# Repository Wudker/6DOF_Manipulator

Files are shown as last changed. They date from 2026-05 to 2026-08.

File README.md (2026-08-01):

# Educational 6-DOF Robotic Manipulator – Engineering Thesis

This project presents an educational anthropomorphic robotic manipulator with six degrees of freedom, developed as an engineering thesis. It combines mechanical design, kinematic analysis, embedded control, custom electronics and software development. The system uses an ESP32 and a custom PCB to control six stepper-driven joints through a local web interface. Forward and inverse kinematics provide position control, while repeatability and positioning tests were used to validate the adopted assumptions and identify the prototype’s mechanical limitations.

## Technologies

`ESP32` `C/C++` `Forward kinematics` `Inverse kinematics` `WebServer` `Stepper motors` `DRV8825` `Custom PCB` `Belt transmissions` `3D printing` `CAD`

## Usage and development status

After assembling the hardware and uploading the firmware, the manipulator can be controlled through its local web interface. Before starting movement, verify the wiring, power supply and initial joint positions. The prototype was successfully built and tested; potential improvements include increased mechanical stiffness, more accurate calibration and smoother trajectory planning.

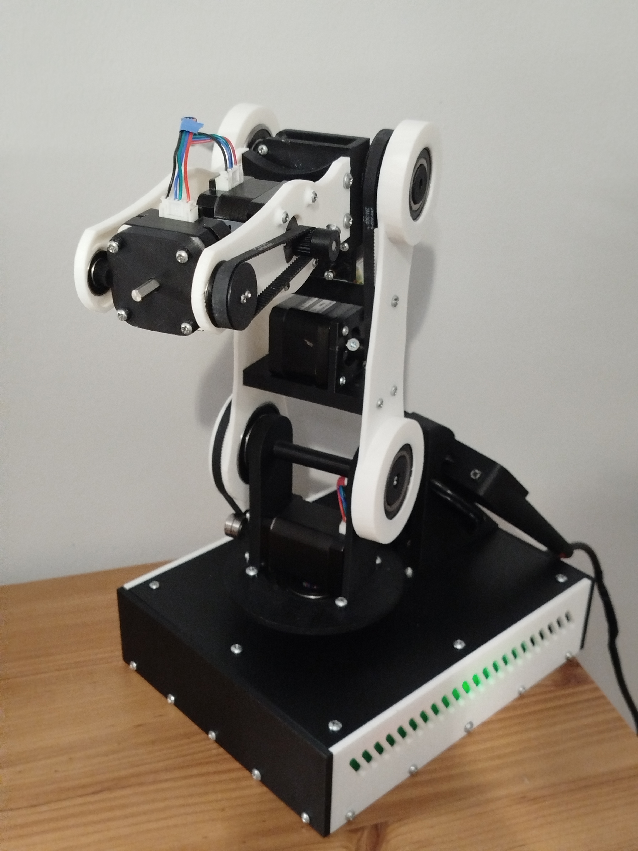
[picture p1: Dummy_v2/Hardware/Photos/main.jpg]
Prototype


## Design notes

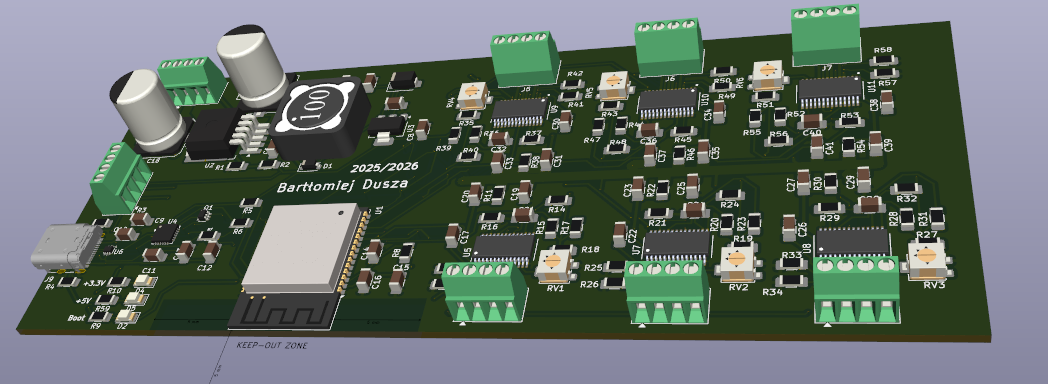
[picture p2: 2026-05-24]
Dummy_v2/Hardware/Photos/PCB_photos/Screenshot_12.png

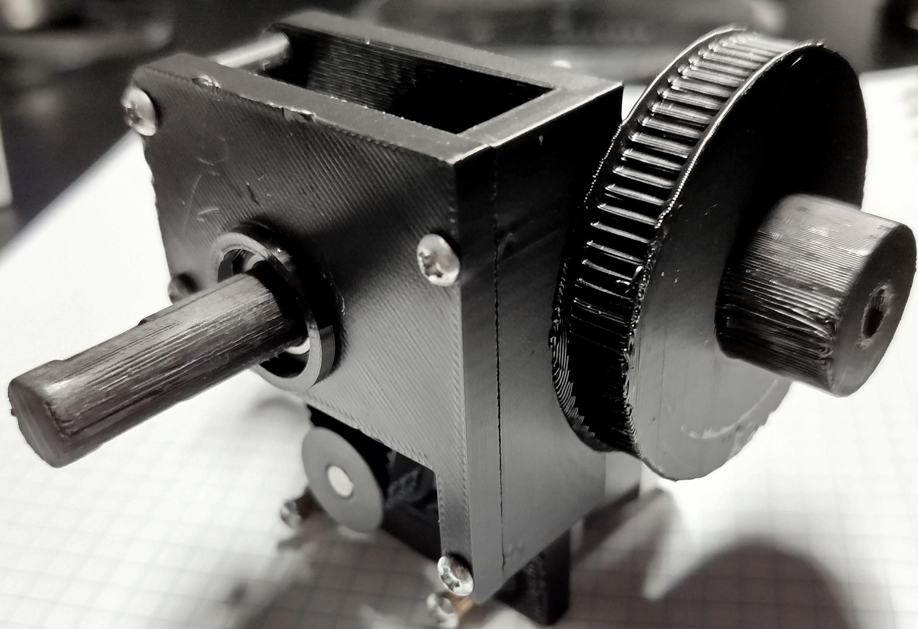
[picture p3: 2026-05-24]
Dummy_v2/Hardware/Photos/real_przegub_4.jpg

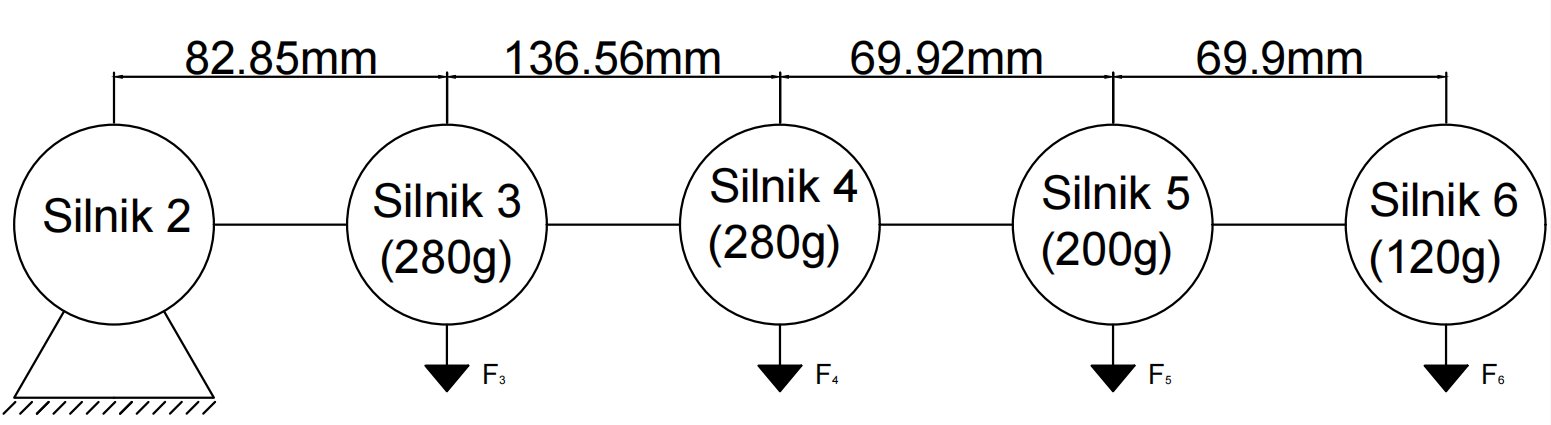
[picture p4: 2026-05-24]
Dummy_v2/Hardware/Photos/momenty_przykład_obliczen.png

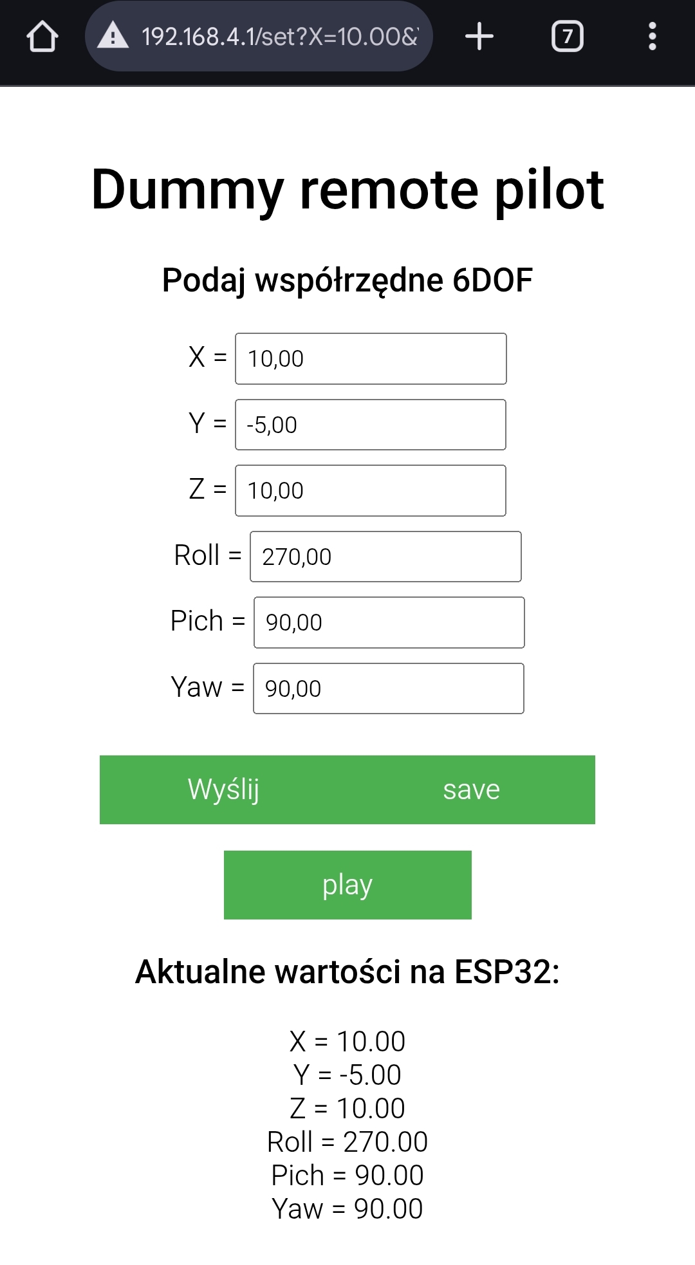
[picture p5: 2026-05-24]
Dummy_v2/Hardware/Photos/Remote (1).jpg

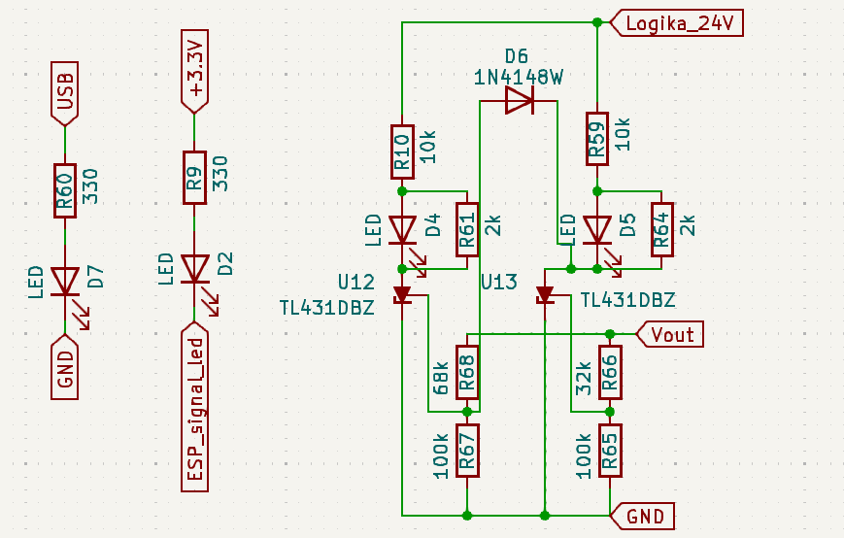
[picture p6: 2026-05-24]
Dummy_v2/Hardware/Photos/PCB_photos/PCB_indycators.png

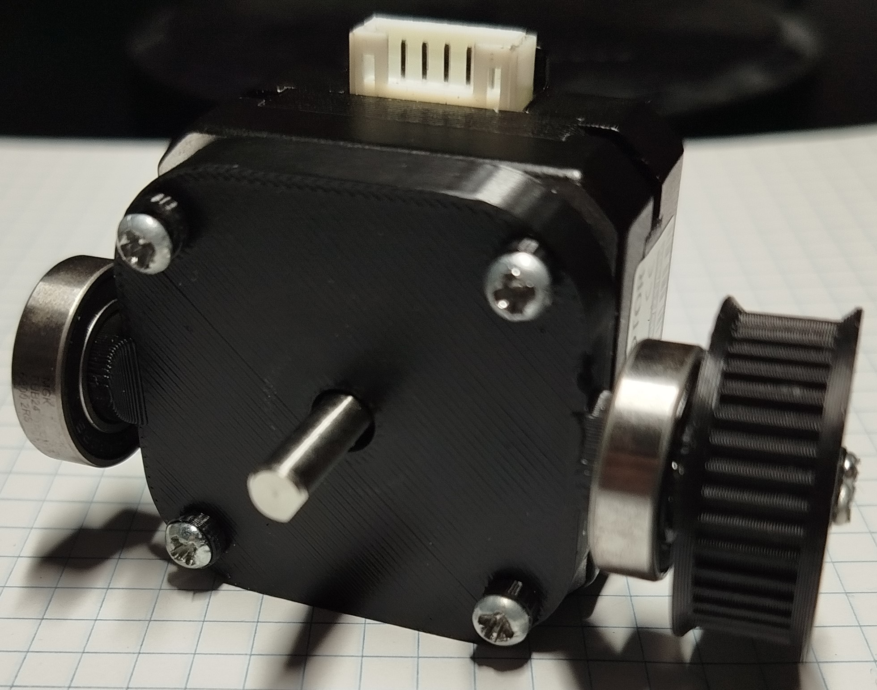
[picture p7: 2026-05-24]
Dummy_v2/Hardware/Photos/real_przegub_6.jpg

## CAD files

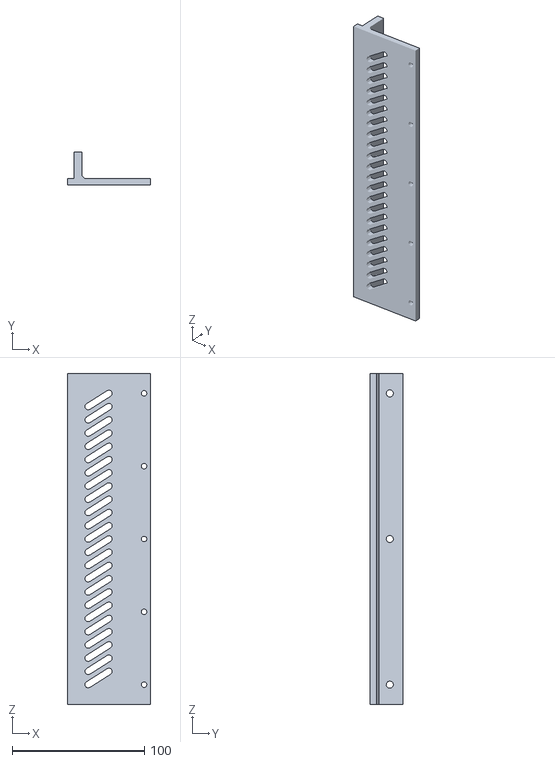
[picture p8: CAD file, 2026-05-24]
Dummy_v2/Hardware/Model/podstawa/podstawa_sciana_bok.stl
63.0 x 25.0 x 250.0

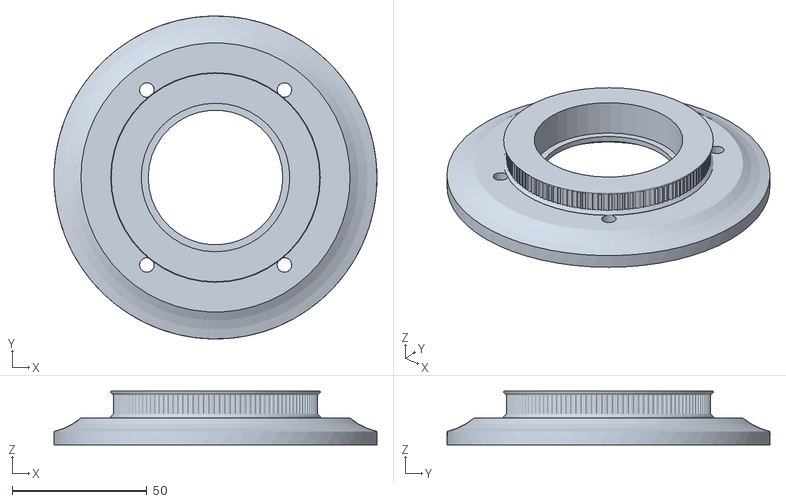
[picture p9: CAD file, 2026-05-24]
Dummy_v2/Hardware/Model/przegub_1/podstawa_platforma.stl
120.0 x 120.0 x 20.0

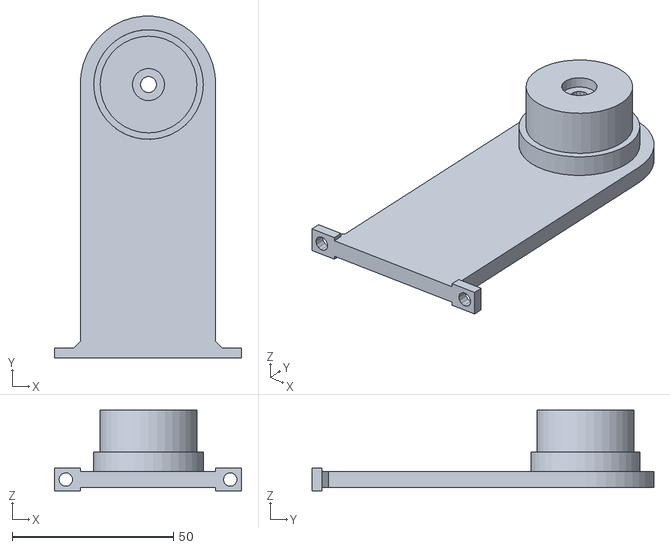
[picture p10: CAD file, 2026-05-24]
Dummy_v2/Hardware/Model/przegub_2/baza_rama_cz2.stl
58.0 x 105.9 x 25.0

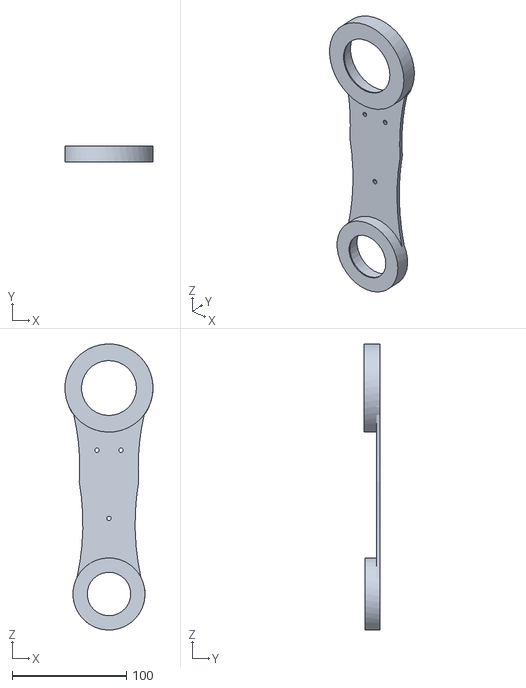
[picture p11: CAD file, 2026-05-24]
Dummy_v2/Hardware/Model/przegub_3/baza_rama3.stl
77.0 x 14.0 x 249.9

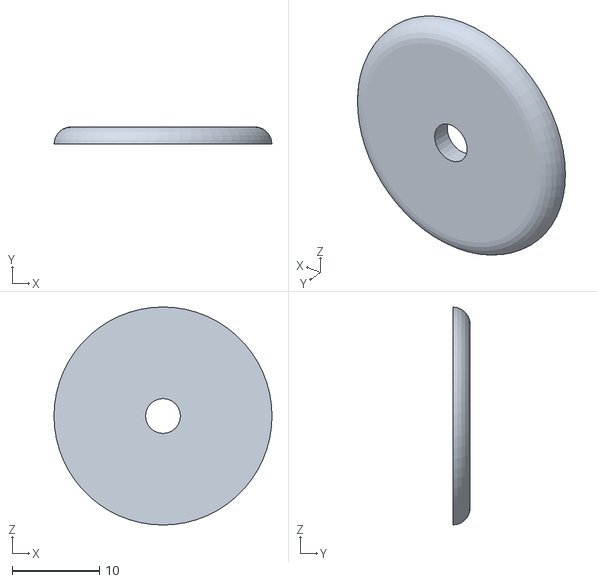
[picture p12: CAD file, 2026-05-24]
Dummy_v2/Hardware/Model/przegub_4/OBUD.stl
25.0 x 2.00 x 25.0

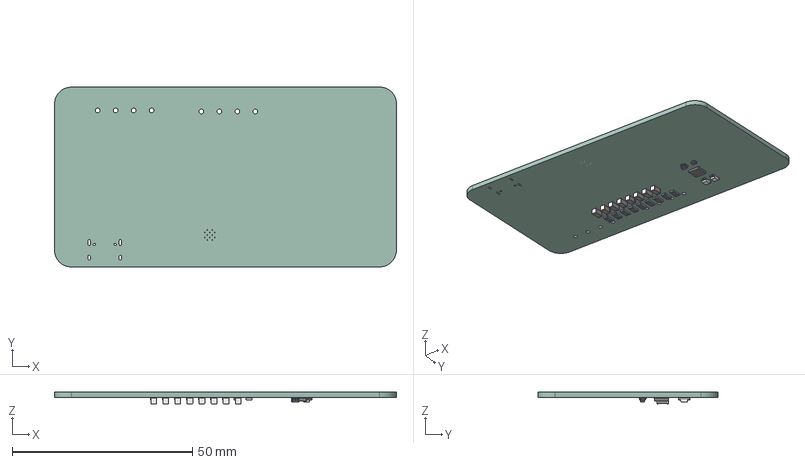
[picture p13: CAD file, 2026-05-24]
Dummy_v2/Hardware/PCB/Pilot/Pilot.step
95.0 x 50.0 x 3.20 mm
C_1206_3216Metric x 8
R_1206_3216Metric x 9
SOT-666
SOT-363_SC-70-6
LED_1206_3216Metric x 2
QFN-24-1EP_4x4mm_P0.5mm_EP2.6x2.6mm
Pilot_PCB

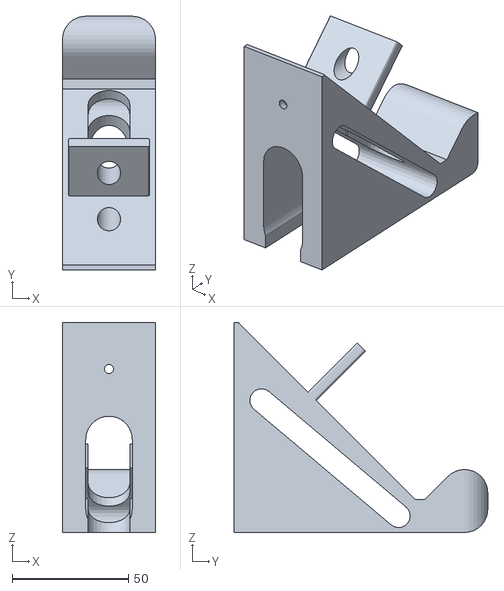
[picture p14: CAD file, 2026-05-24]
Dummy_v2/Hardware/Model/podstawa/podstawka.stl
40.0 x 109.0 x 90.2

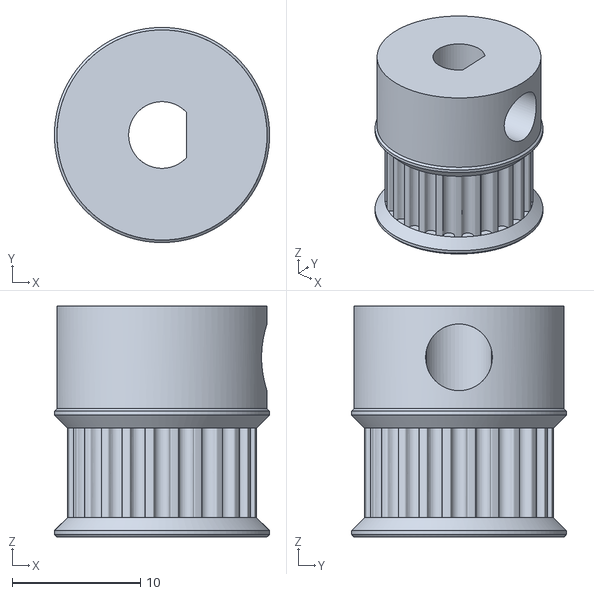
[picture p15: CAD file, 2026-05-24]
Dummy_v2/Hardware/Model/przegub_2/24_zb_baza_v2 v1.stl
16.8 x 16.8 x 18.0

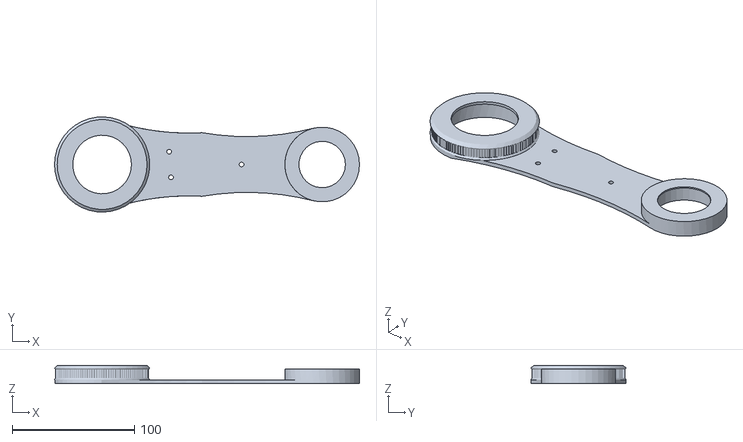
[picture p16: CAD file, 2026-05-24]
Dummy_v2/Hardware/Model/przegub_3/zebma.stl
249.5 x 77.8 x 15.0

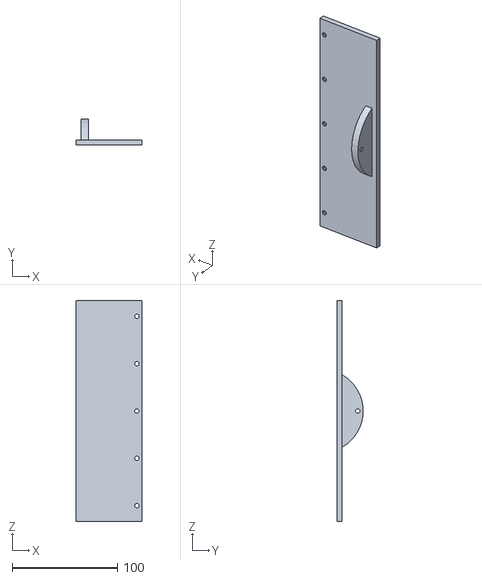
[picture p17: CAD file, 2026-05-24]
Dummy_v2/Hardware/Model/podstawa/podstawa_sciana_front.stl
63.0 x 25.2 x 210.0

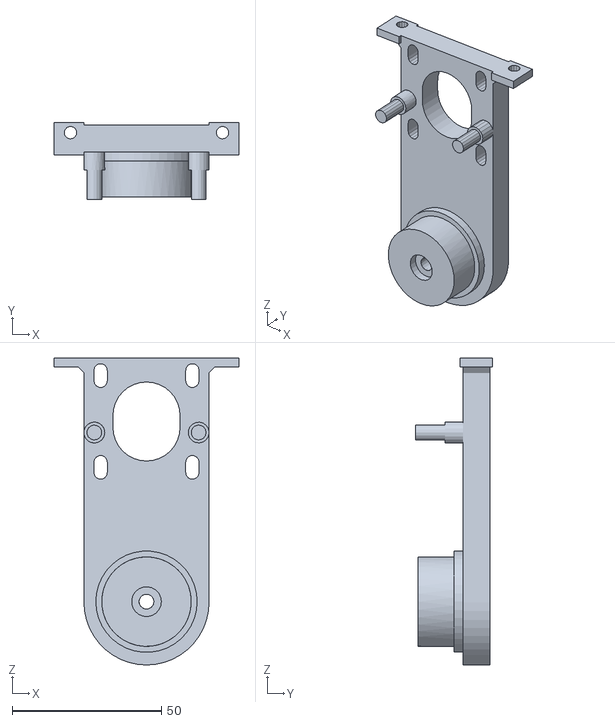
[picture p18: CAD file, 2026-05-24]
Dummy_v2/Hardware/Model/przegub_2/test_ramy2.0.stl
62.0 x 26.0 x 103.0

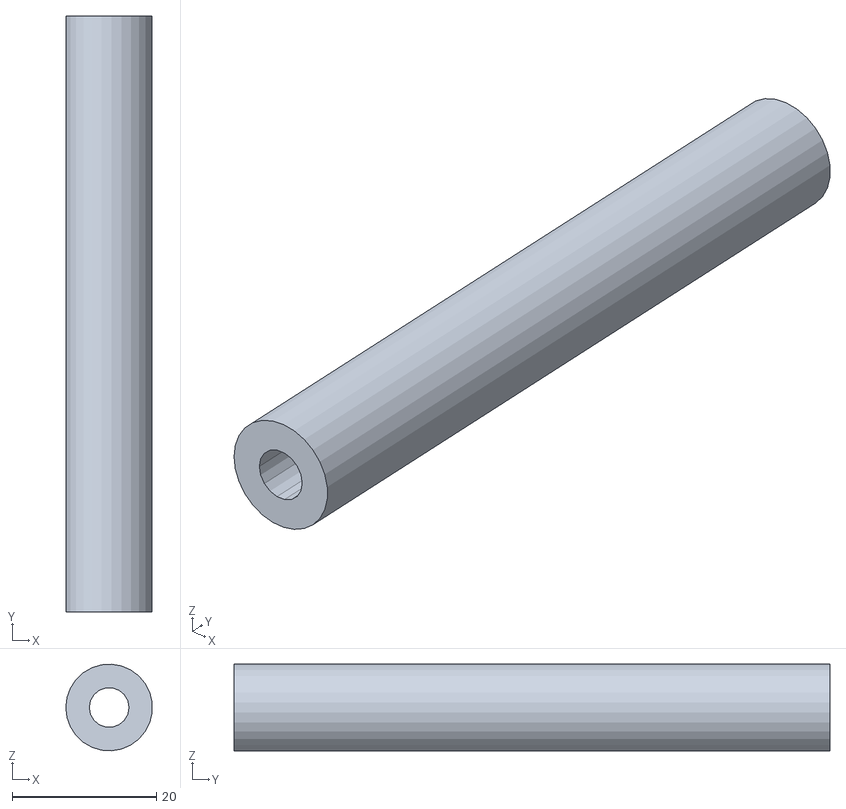
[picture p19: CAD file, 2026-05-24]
Dummy_v2/Hardware/Model/przegub_3/belkamid.stl
12.0 x 82.5 x 12.0

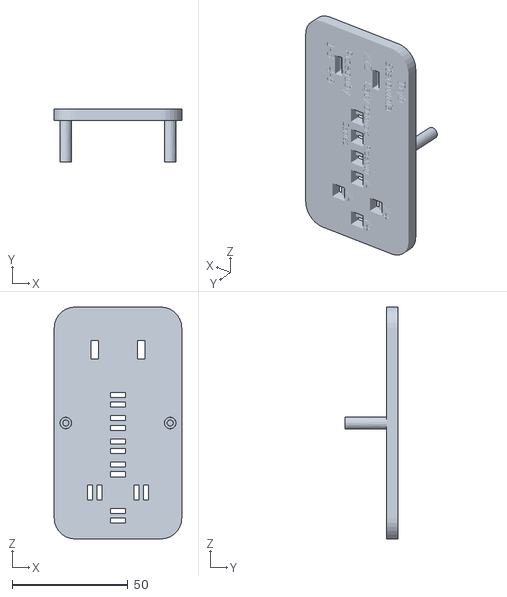
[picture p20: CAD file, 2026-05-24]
Dummy_v2/Hardware/Model/podstawa/kontroler_top.stl
55.0 x 23.0 x 100.0

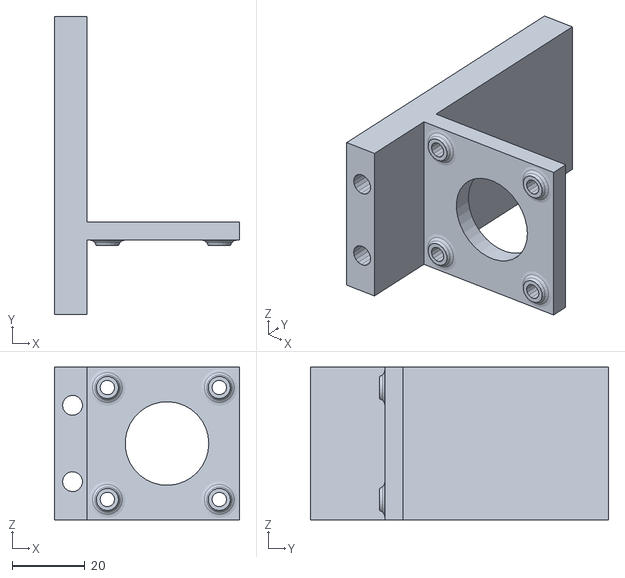
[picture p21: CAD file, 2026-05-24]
Dummy_v2/Hardware/Model/przegub_3/os2_polatforma.stl
51.0 x 82.0 x 42.0

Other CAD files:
Dummy_v2/Hardware/Model/podstawa/skrzynka_na_elektronike.stl
Dummy_v2/Hardware/Model/przegub_3/20_zb_wal.stl
Dummy_v2/Hardware/Model/przegub_2/motor_1_rama.stl
Dummy_v2/Hardware/Model/podstawa/ESP32 wroom 32 v9.step
Dummy_v1/Hardware/Parts/Część4.ipt
Dummy_v1/Hardware/Parts/Część5.ipt
Dummy_v1/Hardware/Parts/Część6.ipt
Dummy_v1/Hardware/Parts/GEAR.dwg
Dummy_v1/Hardware/Parts/GEAR.ipt
Dummy_v1/Hardware/Parts/GEAR_SERV.ipt
Dummy_v1/Hardware/Parts/arm_v1(backup).ipt
Dummy_v1/Hardware/Parts/arm_v1(bez_dokladnych_otworow_montazowych).ipt
Dummy_v1/Hardware/Parts/arm_v2(arm-point).ipt
Dummy_v1/Hardware/Parts/arm_v2(base-arm).ipt
Dummy_v1/Hardware/Parts/arm_v3-1_backup.ipt
Dummy_v1/Hardware/Parts/arm_v3.ipt
Dummy_v1/Hardware/Parts/arm_v3_backup.ipt
Dummy_v1/Hardware/Parts/arr34.dwg
Dummy_v1/Hardware/Parts/assas.ipt
Dummy_v1/Hardware/Parts/baza.ipt
Dummy_v1/Hardware/Parts/baza2.dwg
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

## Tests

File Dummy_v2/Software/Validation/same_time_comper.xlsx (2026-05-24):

bez same_time() |  |  | same_time() |  |  | odleglosc=10cm
os x | os y | os z | os x | os y | os z | jednostki to sekundy
0.86 | 0.86 | 0.84 | 0.89 | 0.83 | 0.9
0.9 | 0.87 | 0.89 | 0.83 | 0.82 | 0.84
0.88 | 0.86 | 0.86 | 0.86 | 0.82 | 0.87
Xstart | (10,-5,10) |  | Xkoncowe | (20,5,20) |  | jednostki to sekundy
1.5 |  |  | 1.23
1.45 |  |  | 1.21
1.47 |  |  | 1.24
 |  | v= | 0.08130081301 | m/s

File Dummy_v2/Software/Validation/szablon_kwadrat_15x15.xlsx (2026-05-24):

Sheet: Kwadrat_15x15
Nr pomiaru | Linia 1 [mm] | Linia 2 [mm] | Linia 3 [mm] | Linia 4 [mm] | L_nom [mm] | 15
Pomiar 1 | 15.38 | 15.8 | 15.8 | 15.5
Pomiar 2 | 15.5 | 15.6 | 15.5 | 16
Pomiar 3 | 14.9 | 15.75 | 15.72 | 15.6
Pomiar 4 | 15.13 | 15.3 | 15.2 | 15.9
 | 15.2275 | 15.6125 | 15.555 | 15.75
Średnia L̄ [mm] | 15.2275 | 15.6125 | 15.555 | 15.75
Błąd średni ē [mm] | 0.2275 | 0.6125 | 0.555 | 0.75
Błąd średni ē [%] | 1.516666667 | 4.083333333 | 3.7 | 5
Odchylenie standardowe s [mm] | 0.2672545603 | 0.225 | 0.2685144316 | 0.2380476143
Współczynnik skali k = L̄/L_nom | 1.015166667 | 1.040833333 | 1.037 | 1.05
Max |e| [mm] | #VALUE! | #VALUE! | #VALUE! | #VALUE!
MAE [mm] | 45.2775 | 45.6125 | 45.555 | 45.75
RMSE [mm] | 25.98278902 | 25.98871149 | 25.9877298 | 25.99240274
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

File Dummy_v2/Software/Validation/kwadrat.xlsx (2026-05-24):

pomiar | linia 1 | linia 2 | linia 3 | linia 4
 | mm | mm | mm | mm
1 | 15.38 | 15.8 | 15.8 | 15.5
2 | 15.5 | 15.6 | 15.5 | 16
3 | 14.9 | 15.75 | 15.72 | 15.6
4 | 15.13 | 15.3 | 15.2 | 15.9

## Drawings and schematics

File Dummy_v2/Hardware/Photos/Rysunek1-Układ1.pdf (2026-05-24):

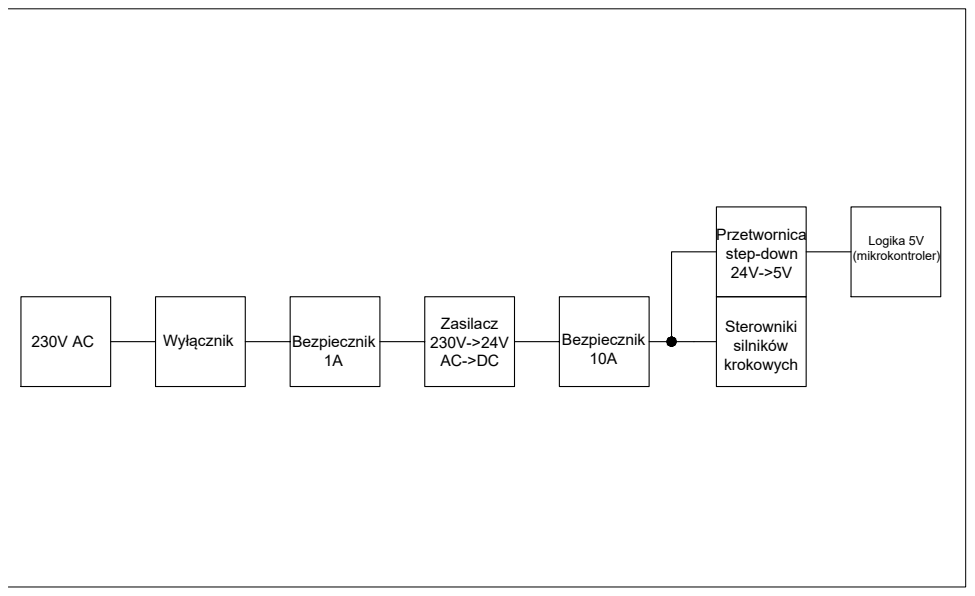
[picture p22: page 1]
Wyłącznik; Bezpiecznik; Logika 5V

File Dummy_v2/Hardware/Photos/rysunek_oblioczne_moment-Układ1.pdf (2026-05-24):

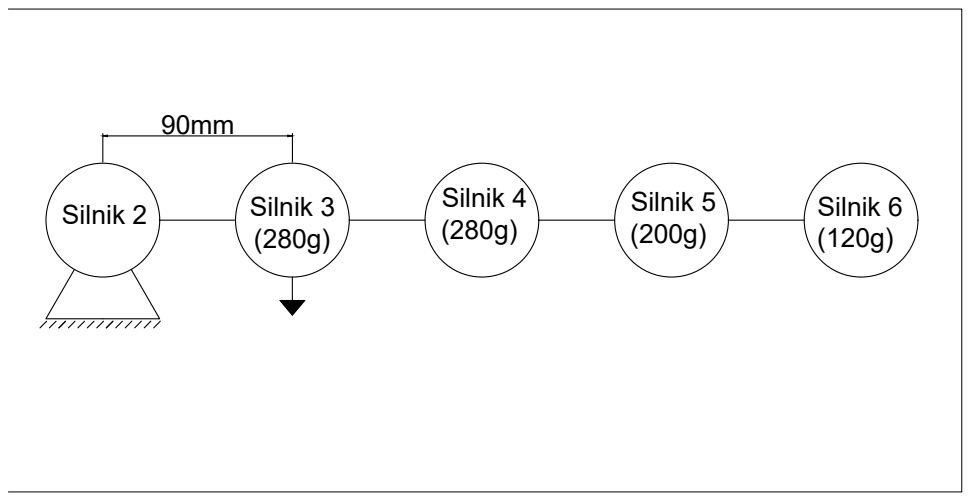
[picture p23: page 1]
Silnik 2; Silnik 3; Silnik 4; Silnik 5; Silnik 6

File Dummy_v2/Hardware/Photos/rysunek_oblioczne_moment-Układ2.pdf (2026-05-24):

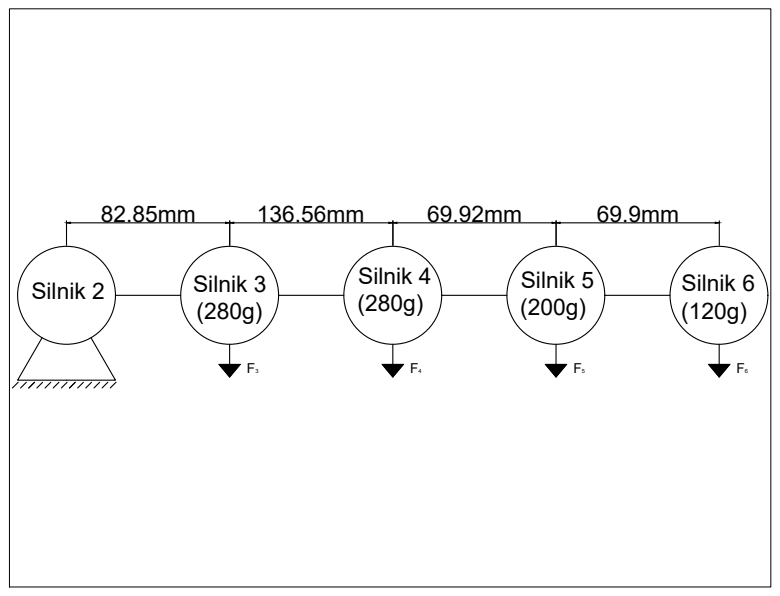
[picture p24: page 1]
Silnik 2; Silnik 3; Silnik 4; Silnik 5; Silnik 6

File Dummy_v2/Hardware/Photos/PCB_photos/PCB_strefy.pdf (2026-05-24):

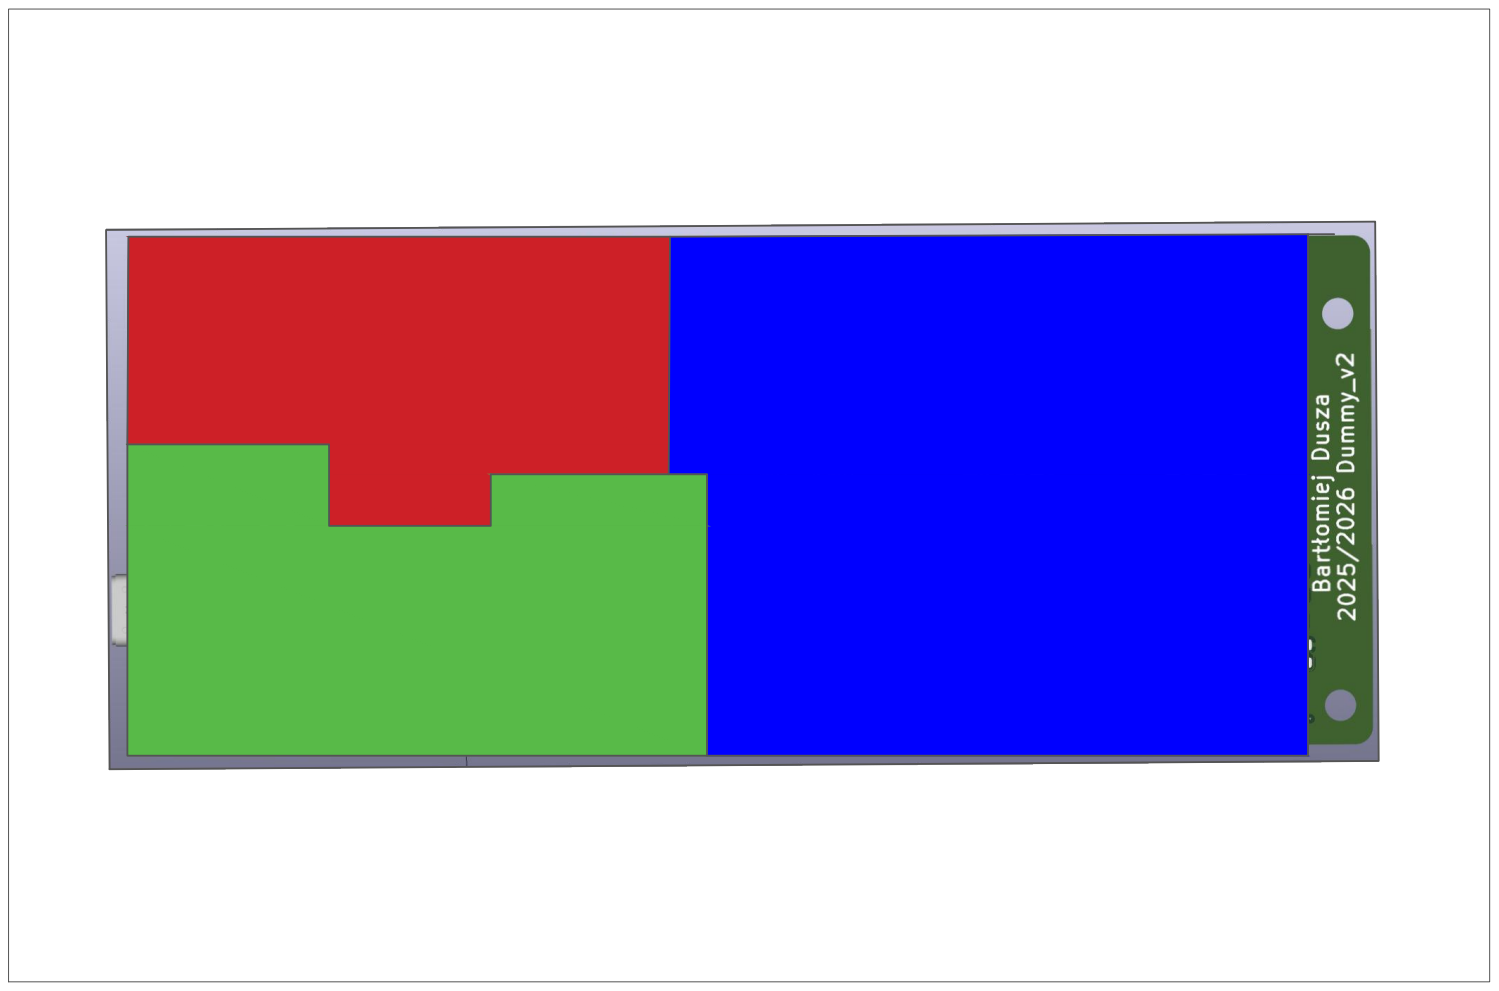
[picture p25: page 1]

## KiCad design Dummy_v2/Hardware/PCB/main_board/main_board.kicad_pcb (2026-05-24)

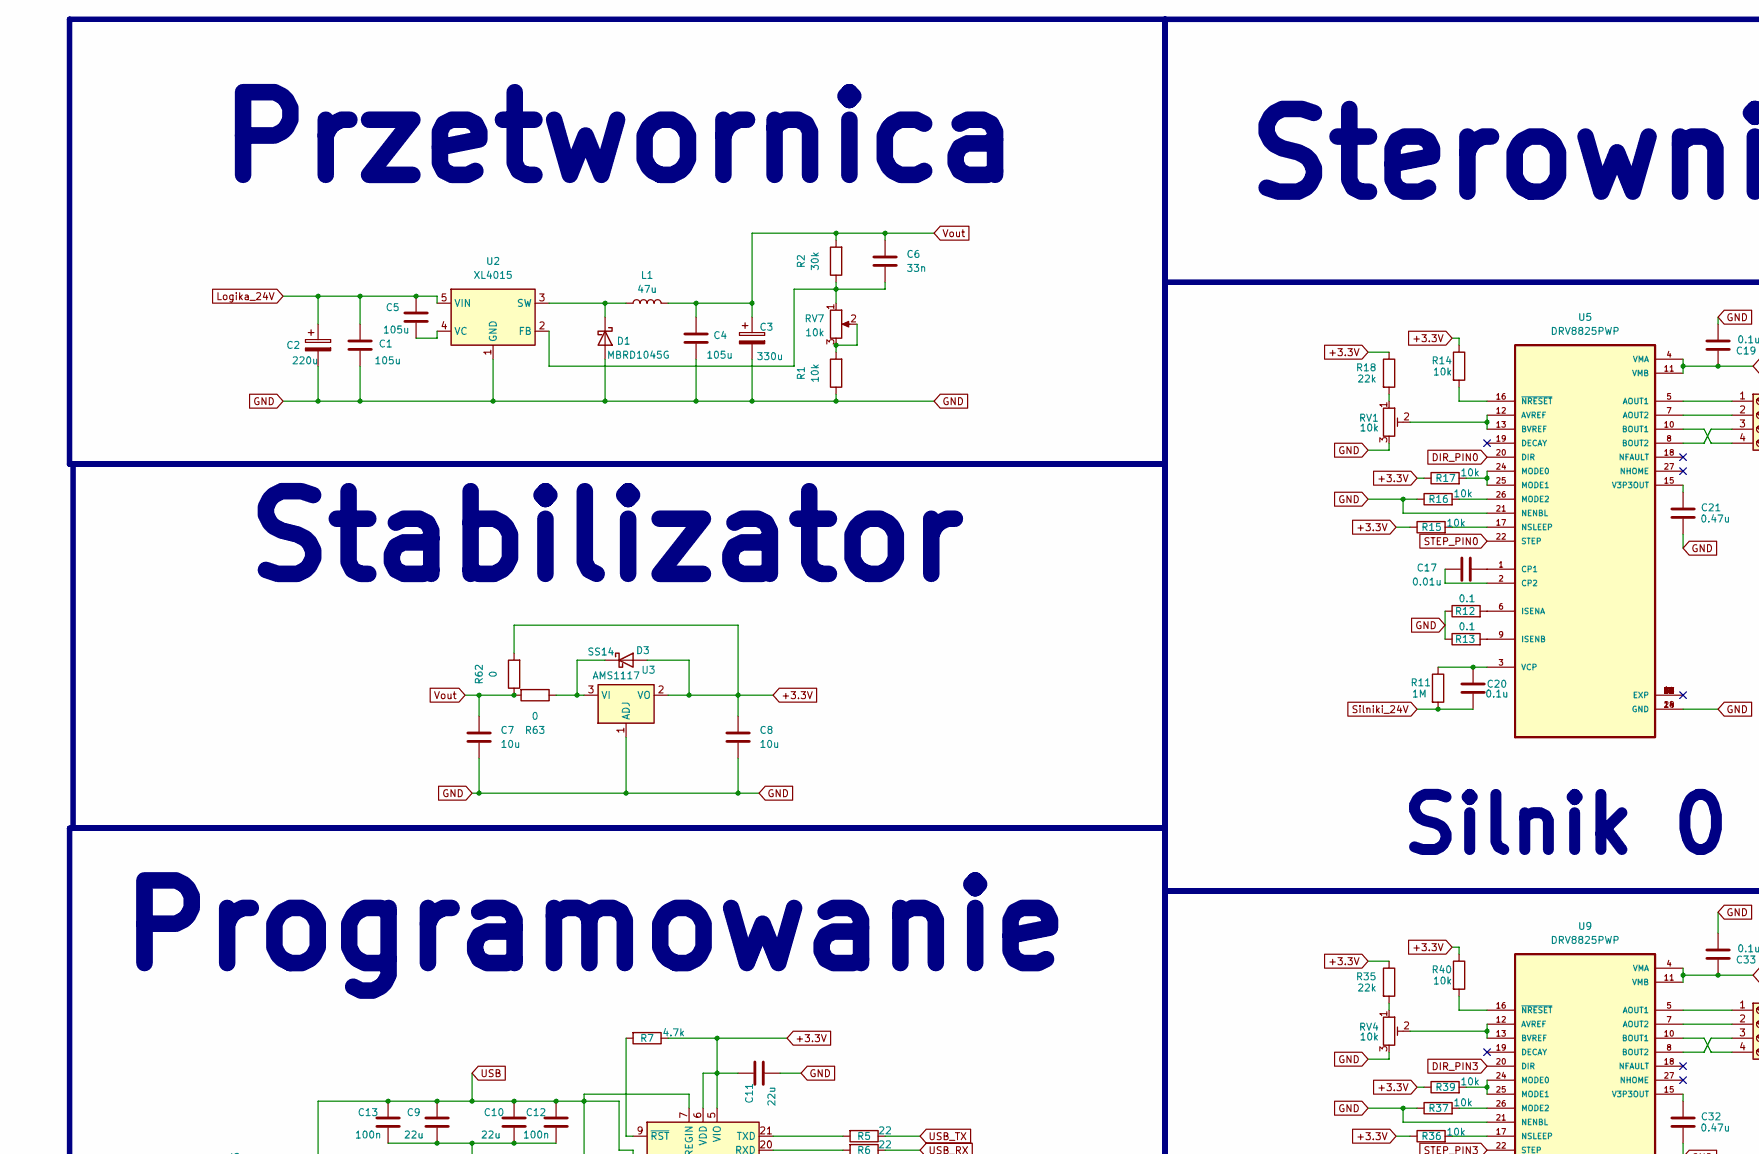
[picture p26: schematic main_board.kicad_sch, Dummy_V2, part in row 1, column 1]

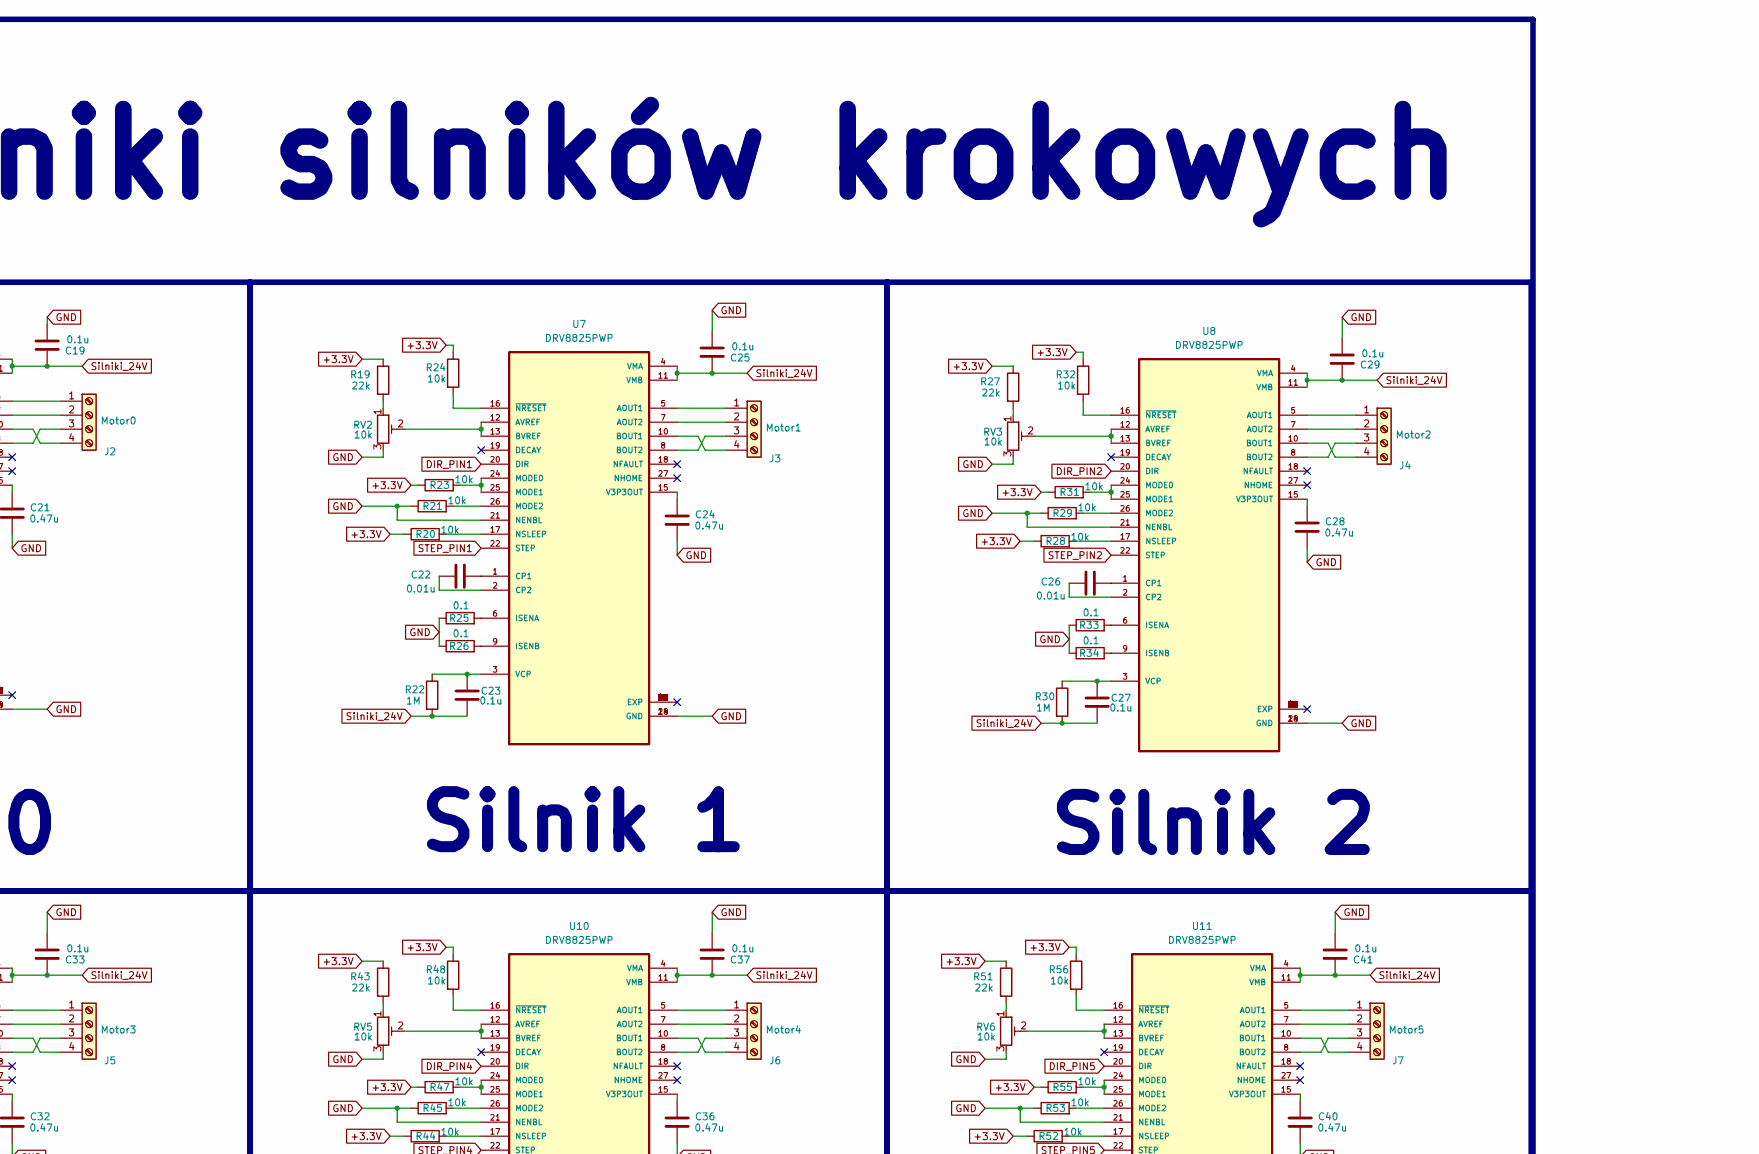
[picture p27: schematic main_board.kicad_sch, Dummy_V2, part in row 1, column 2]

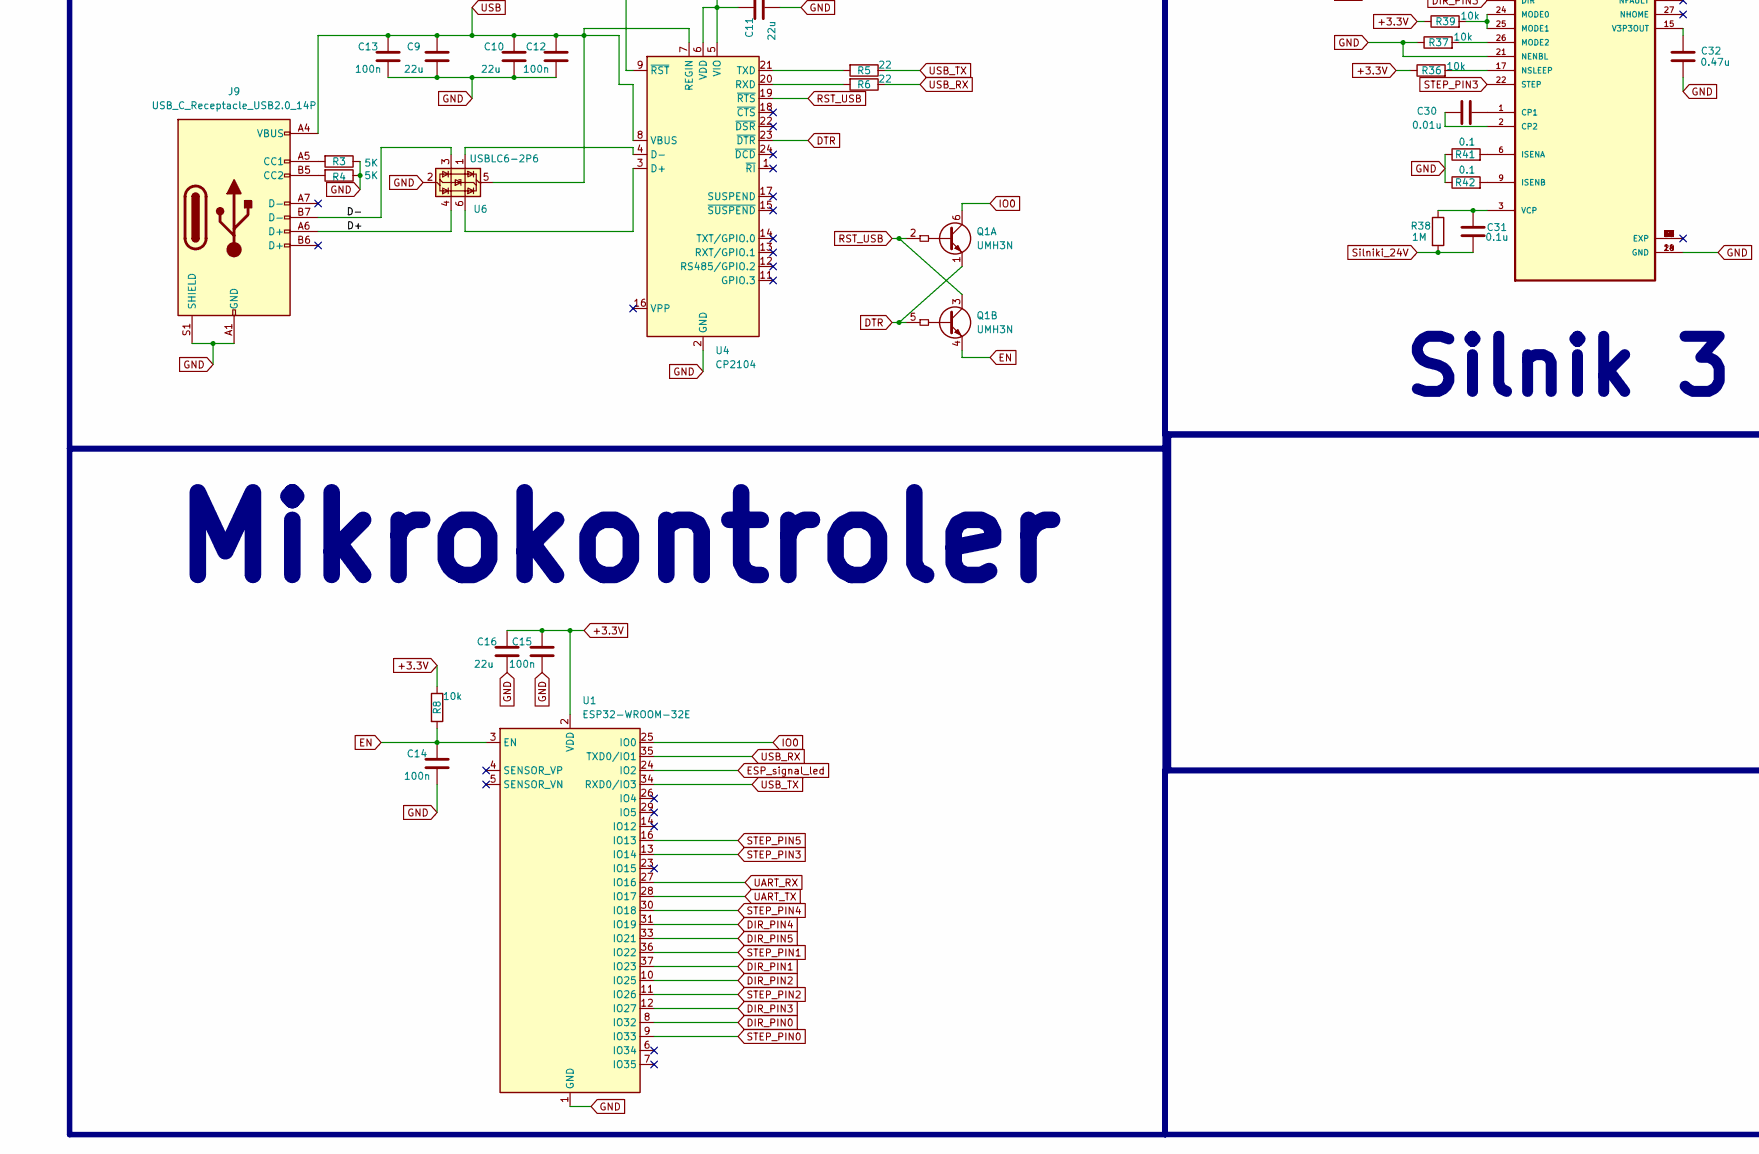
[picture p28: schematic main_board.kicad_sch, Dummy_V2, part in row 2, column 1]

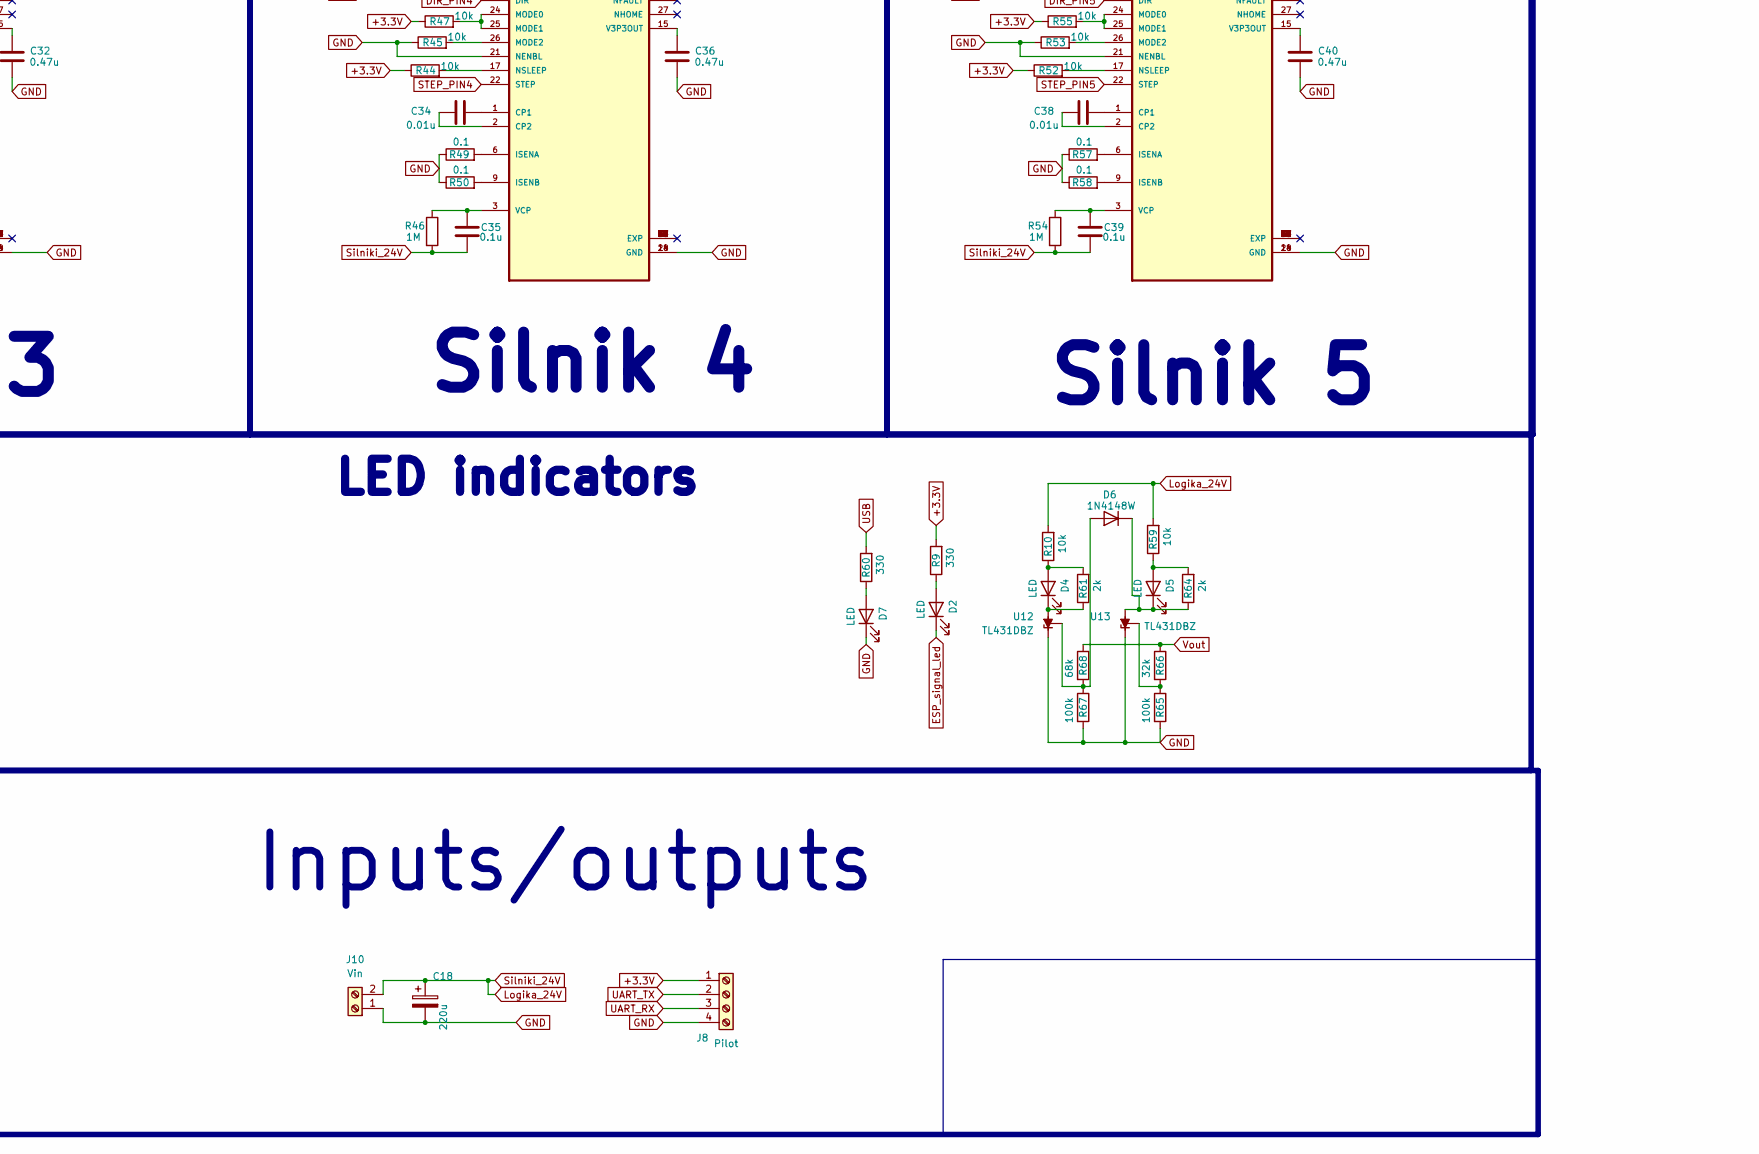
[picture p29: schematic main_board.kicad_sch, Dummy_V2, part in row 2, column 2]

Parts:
C1, C4, C5: 105u; C_1206_3216Metric_Pad1.33x1.80mm_HandSolder
C2, C18: 220u; CP_Elec_10x14.3
C3: 330u; C_1206_3216Metric_Pad1.33x1.80mm_HandSolder
C6: 33n; C_1206_3216Metric_Pad1.33x1.80mm_HandSolder
C7, C8: 10u; C_1206_3216Metric_Pad1.33x1.80mm_HandSolder
C9, C10, C11, C16: 22u; C_1206_3216Metric_Pad1.33x1.80mm_HandSolder
C12, C13, C14, C15: 100n; C_1206_3216Metric_Pad1.33x1.80mm_HandSolder
C17, C22, C26, C30, C34, C38: 0.01u; C_1206_3216Metric_Pad1.33x1.80mm_HandSolder
C19, C20, C23, C25, C27, C29, C31, C33, C35, C37, C39, C41: 0.1u; C_1206_3216Metric_Pad1.33x1.80mm_HandSolder
C21, C24, C28, C32, C36, C40: 0.47u; C_1206_3216Metric_Pad1.33x1.80mm_HandSolder
D1: MBRD1045G; D_SOD-123
D2, D4, D5, D7: LED; LED_1206_3216Metric
D3: SS14; D_SMA
D6: 1N4148W; D_SOD-123
J2: Motor0; TerminalBlock_Phoenix_MPT-0,5-4-2.54_1x04_P2.54mm_Horizontal
J3: Motor1; TerminalBlock_Phoenix_MPT-0,5-4-2.54_1x04_P2.54mm_Horizontal
J4: Motor2; TerminalBlock_Phoenix_MPT-0,5-4-2.54_1x04_P2.54mm_Horizontal
J5: Motor3; TerminalBlock_Phoenix_MPT-0,5-4-2.54_1x04_P2.54mm_Horizontal
J6: Motor4; TerminalBlock_Phoenix_MPT-0,5-4-2.54_1x04_P2.54mm_Horizontal
J7: Motor5; TerminalBlock_Phoenix_MPT-0,5-4-2.54_1x04_P2.54mm_Horizontal
J8: Pilot; TerminalBlock_Phoenix_MPT-0,5-4-2.54_1x04_P2.54mm_Horizontal
J9: USB_C_Receptacle_USB2.0_14P; USB_C_Receptacle_G-Switch_GT-USB-7010ASV
J10: Vin; TerminalBlock_MetzConnect_Type055_RT01502HDWU_1x02_P5.00mm_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
L1: 47u; L_12x12mm_H4.5mm
Q1: UMH3N; SOT-363_SC-70-6
R1, R8, R10, R14, R15, R16, R17, R20, R21, R23, R24, R28, R29, R31, R32, R36, R37, R39, R40, R44, R45, R47, R48, R52, R53, R55, R56, R59: 10k; R_1206_3216Metric_Pad1.30x1.75mm_HandSolder
R2: 30k; R_1206_3216Metric_Pad1.30x1.75mm_HandSolder
R3, R4: 5K; R_1206_3216Metric_Pad1.30x1.75mm_HandSolder
R5, R6: 22; R_1206_3216Metric_Pad1.30x1.75mm_HandSolder
R7: 4.7k; R_1206_3216Metric_Pad1.30x1.75mm_HandSolder
R9, R60: 330; R_1206_3216Metric_Pad1.30x1.75mm_HandSolder
R11, R22, R30, R38, R46, R54: 1M; R_1206_3216Metric_Pad1.30x1.75mm_HandSolder
R12, R13, R25, R26, R33, R34, R41, R42, R49, R50, R57, R58: 0.1; R_1206_3216Metric_Pad1.30x1.75mm_HandSolder
R18, R19, R27, R35, R43, R51: 22k; R_1206_3216Metric_Pad1.30x1.75mm_HandSolder
R61, R64: 2k; R_1206_3216Metric_Pad1.30x1.75mm_HandSolder
R62, R63: 0; R_1206_3216Metric_Pad1.30x1.75mm_HandSolder
R65, R67: 100k; R_1206_3216Metric_Pad1.30x1.75mm_HandSolder
R66: 32k; R_1206_3216Metric_Pad1.30x1.75mm_HandSolder
R68: 68k; R_1206_3216Metric_Pad1.30x1.75mm_HandSolder
RV1, RV2, RV3, RV4, RV5, RV6: 10k; Potentiometer_Bourns_3314G_Vertical
RV7: 10k; Potentiometer_Bourns_3214J_Horizontal
U1: ESP32-WROOM-32E; ESP32-WROOM-32D
U2: XL4015; TO-263-5_TabPin3
U3: AMS1117; SOT-223-3_TabPin2
U4: CP2104; QFN-24-1EP_4x4mm_P0.5mm_EP2.6x2.6mm
U5, U7, U8, U9, U10, U11: DRV8825PWP; IC_TPS61196PWPRQ1
U6: USBLC6-2P6; SOT-666
U12, U13: TL431DBZ; SOT-23

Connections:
+3.3V: C8.1, C11.1, C15.1, C16.1, D3.2 (A), J8.1, R7.1, R8.1, R9.2, R14.1, R15.1, R17.1, R18.1, R19.1, R20.1, R23.1, R24.1, R27.1, R28.1, R31.1, R32.1, R35.1, R36.1, R39.1, R40.1, R43.1, R44.1, R47.1, R48.1, R51.1, R52.1, R55.1, R56.1, R62.2, U1.2 (VDD), U3.2 (VO), U4.5 (VIO), U4.6 (VDD)
/D+: J9.A6 (D+), U6.4 (I/O2)
/D-: J9.B7 (D-), U6.3 (I/O2)
DIR_PIN0: U1.8 (IO32), U5.20 (DIR)
DIR_PIN1: U1.37 (IO23), U7.20 (DIR)
DIR_PIN2: U1.10 (IO25), U8.20 (DIR)
DIR_PIN3: U1.12 (IO27), U9.20 (DIR)
DIR_PIN4: U1.31 (IO19), U10.20 (DIR)
DIR_PIN5: U1.33 (IO21), U11.20 (DIR)
DTR: Q1.1 (E1), Q1.5 (B2), U4.23 (~DTR)
EN: C14.1, Q1.4 (E2), R8.2, U1.3 (EN)
ESP_signal_led: D2.1 (K), U1.24 (IO2)
GND: C1.2, C2.2, C3.2, C4.2, C7.2, C8.2, C9.2, C10.2, C11.2, C12.2, C13.2, C14.2, C15.2, C16.2, C18.2, C19.1, C21.1, C24.1, C25.1, C28.1, C29.1, C32.1, C33.1, C36.1, C37.1, C40.1, C41.1, D1.2 (A), D7.1 (K), J8.4, J9.A1 (GND), J9.A12 (GND), J9.B1 (GND), J9.B12 (GND), J9.S1 (SHIELD), J10.1, R1.1, R3.1, R4.1, R12.1, R13.1, R16.1, R21.1, R25.1, R26.1, R29.1, R33.1, R34.1, R37.1, R41.1, R42.1, R45.1, R49.1, R50.1, R53.1, R57.1, R58.1, R65.2, R67.2, RV1.3, RV2.3, RV3.3, RV4.3, RV5.3, RV6.3, U1.1 (GND), U1.15 (GND), U1.38 (GND), U1.39 (GND), U2.1 (GND), U3.1 (ADJ), U4.2 (GND), U4.25 (GND), U5.14 (GND), U5.21 (NENBL), U5.28 (GND), U6.2 (GND), U7.14 (GND), U7.21 (NENBL), U7.28 (GND), U8.14 (GND), U8.21 (NENBL), U8.28 (GND), U9.14 (GND), U9.21 (NENBL), U9.28 (GND), U10.14 (GND), U10.21 (NENBL), U10.28 (GND), U11.14 (GND), U11.21 (NENBL), U11.28 (GND), U12.1 (K), U13.1 (K)
IO0: Q1.6 (C1), U1.25 (IO0)
Logika_24V: C1.1, C2.1, C5.1, C18.1, C19.2, C20.2, C23.2, C25.2, C27.2, C29.2, C31.2, C33.2, C35.2, C37.2, C39.2, C41.2, J10.2, R10.2, R11.2, R22.2, R30.2, R38.2, R46.2, R54.2, R59.2, U2.5 (VIN), U5.4 (VMA), U5.11 (VMB), U7.4 (VMA), U7.11 (VMB), U8.4 (VMA), U8.11 (VMB), U9.4 (VMA), U9.11 (VMB), U10.4 (VMA), U10.11 (VMB), U11.4 (VMA), U11.11 (VMB)
unnamed: D1.1 (K), L1.1, U2.3 (SW)
unnamed: D2.2 (A), R9.1
unnamed: D3.1 (K), R63.1, U3.3 (VI)
unnamed: D4.2 (A), R10.1, R61.2
unnamed: D4.1 (K), R61.1, U12.3 (A)
unnamed: D5.2 (A), R59.1, R64.2
unnamed: D5.1 (K), D6.1 (K), R64.1, U13.3 (A)
unnamed: D6.2 (A), R67.1, R68.2, U12.2 (REF)
unnamed: D7.2 (A), R60.1
unnamed: J2.1, U5.5 (AOUT1)
unnamed: J2.2, U5.7 (AOUT2)
unnamed: J2.3, U5.8 (BOUT2)
unnamed: J2.4, U5.10 (BOUT1)
unnamed: J3.1, U7.5 (AOUT1)
unnamed: J3.2, U7.7 (AOUT2)
unnamed: J3.3, U7.8 (BOUT2)
unnamed: J3.4, U7.10 (BOUT1)
unnamed: J4.1, U8.5 (AOUT1)
unnamed: J4.2, U8.7 (AOUT2)
unnamed: J4.3, U8.8 (BOUT2)
unnamed: J4.4, U8.10 (BOUT1)
unnamed: J5.1, U9.5 (AOUT1)
unnamed: J5.2, U9.7 (AOUT2)
unnamed: J5.3, U9.8 (BOUT2)
unnamed: J5.4, U9.10 (BOUT1)
unnamed: J6.1, U10.5 (AOUT1)
unnamed: J6.2, U10.7 (AOUT2)
unnamed: J6.3, U10.8 (BOUT2)
unnamed: J6.4, U10.10 (BOUT1)
unnamed: J7.1, U11.5 (AOUT1)
unnamed: J7.2, U11.7 (AOUT2)
unnamed: J7.3, U11.8 (BOUT2)
unnamed: J7.4, U11.10 (BOUT1)
unnamed: J9.A5 (CC1), R3.2
unnamed: J9.B5 (CC2), R4.2
unnamed: R1.2, RV7.2, RV7.3
unnamed: R18.2, RV1.1
unnamed: R19.2, RV2.1
unnamed: R27.2, RV3.1
unnamed: R35.2, RV4.1
unnamed: R43.2, RV5.1
unnamed: R51.2, RV6.1
unnamed: C6.2, R2.1, RV7.1, U2.2 (FB)
unnamed: C5.2, U2.4 (VC)
unnamed: U4.3 (D+), U6.6 (I/O1)
unnamed: U4.4 (D-), U6.1 (I/O1)
unnamed: R6.2, U4.20 (RXD)
unnamed: R5.2, U4.21 (TXD)
unnamed: R7.2, U4.9 (~RST)
unnamed: RV1.2, U5.12 (AVREF), U5.13 (BVREF)
unnamed: C17.1, U5.1 (CP1)
unnamed: C17.2, U5.2 (CP2)
unnamed: R12.2, U5.6 (ISENA)
unnamed: R13.2, U5.9 (ISENB)
unnamed: R17.2, U5.24 (MODE0), U5.25 (MODE1)
unnamed: R16.2, U5.26 (MODE2)
unnamed: R15.2, U5.17 (NSLEEP)
unnamed: C21.2, U5.15 (V3P3OUT)
unnamed: C20.1, R11.1, U5.3 (VCP)
unnamed: R14.2, U5.16 (~NRESET)
unnamed: RV2.2, U7.12 (AVREF), U7.13 (BVREF)
unnamed: C22.1, U7.1 (CP1)
unnamed: C22.2, U7.2 (CP2)
unnamed: R25.2, U7.6 (ISENA)
unnamed: R26.2, U7.9 (ISENB)
unnamed: R23.2, U7.24 (MODE0), U7.25 (MODE1)
unnamed: R21.2, U7.26 (MODE2)
unnamed: R20.2, U7.17 (NSLEEP)
unnamed: C24.2, U7.15 (V3P3OUT)
unnamed: C23.1, R22.1, U7.3 (VCP)
unnamed: R24.2, U7.16 (~NRESET)
unnamed: RV3.2, U8.12 (AVREF), U8.13 (BVREF)
unnamed: C26.1, U8.1 (CP1)
unnamed: C26.2, U8.2 (CP2)
unnamed: R33.2, U8.6 (ISENA)
unnamed: R34.2, U8.9 (ISENB)
unnamed: R31.2, U8.24 (MODE0), U8.25 (MODE1)
unnamed: R29.2, U8.26 (MODE2)
unnamed: R28.2, U8.17 (NSLEEP)
unnamed: C28.2, U8.15 (V3P3OUT)
unnamed: C27.1, R30.1, U8.3 (VCP)
unnamed: R32.2, U8.16 (~NRESET)
unnamed: RV4.2, U9.12 (AVREF), U9.13 (BVREF)
unnamed: C30.1, U9.1 (CP1)
unnamed: C30.2, U9.2 (CP2)
unnamed: R41.2, U9.6 (ISENA)
unnamed: R42.2, U9.9 (ISENB)
unnamed: R39.2, U9.24 (MODE0), U9.25 (MODE1)
unnamed: R37.2, U9.26 (MODE2)
unnamed: R36.2, U9.17 (NSLEEP)
unnamed: C32.2, U9.15 (V3P3OUT)
unnamed: C31.1, R38.1, U9.3 (VCP)
unnamed: R40.2, U9.16 (~NRESET)
unnamed: RV5.2, U10.12 (AVREF), U10.13 (BVREF)
unnamed: C34.1, U10.1 (CP1)
unnamed: C34.2, U10.2 (CP2)
unnamed: R49.2, U10.6 (ISENA)
unnamed: R50.2, U10.9 (ISENB)
unnamed: R47.2, U10.24 (MODE0), U10.25 (MODE1)
unnamed: R45.2, U10.26 (MODE2)
unnamed: R44.2, U10.17 (NSLEEP)
unnamed: C36.2, U10.15 (V3P3OUT)
unnamed: C35.1, R46.1, U10.3 (VCP)
unnamed: R48.2, U10.16 (~NRESET)
unnamed: RV6.2, U11.12 (AVREF), U11.13 (BVREF)
unnamed: C38.1, U11.1 (CP1)
unnamed: C38.2, U11.2 (CP2)
unnamed: R57.2, U11.6 (ISENA)
unnamed: R58.2, U11.9 (ISENB)
unnamed: R55.2, U11.24 (MODE0), U11.25 (MODE1)
unnamed: R53.2, U11.26 (MODE2)
unnamed: R52.2, U11.17 (NSLEEP)
unnamed: C40.2, U11.15 (V3P3OUT)
unnamed: C39.1, R54.1, U11.3 (VCP)
unnamed: R56.2, U11.16 (~NRESET)
unnamed: R65.1, R66.2, U13.2 (REF)
RST_USB: Q1.2 (B1), Q1.3 (C2), U4.19 (~RTS)
STEP_PIN0: U1.9 (IO33), U5.22 (STEP)
STEP_PIN1: U1.36 (IO22), U7.22 (STEP)
STEP_PIN2: U1.11 (IO26), U8.22 (STEP)
STEP_PIN3: U1.13 (IO14), U9.22 (STEP)
STEP_PIN4: U1.30 (IO18), U10.22 (STEP)
STEP_PIN5: U1.16 (IO13), U11.22 (STEP)
UART_RX: J8.3, U1.27 (IO16)
UART_TX: J8.2, U1.28 (IO17)
USB: C9.1, C10.1, C12.1, C13.1, J9.A4 (VBUS), J9.A9 (VBUS), J9.B4 (VBUS), J9.B9 (VBUS), R60.2, U4.7 (REGIN), U4.8 (VBUS), U6.5 (VBUS)
USB_RX: R6.1, U1.35 (TXD0/IO1)
USB_TX: R5.1, U1.34 (RXD0/IO3)
Vout: C3.1, C4.1, C6.1, C7.1, L1.2, R2.2, R62.1, R63.2, R66.1, R68.1

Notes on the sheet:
Programowanie
Mikrokontroler
Inputs/outputs
LED indicators
Sterowniki silników krokowych
Stabilizator
Silnik 1
Silnik 2
Silnik 0
Przetwornica
Silnik 4
Silnik 3
Silnik 5

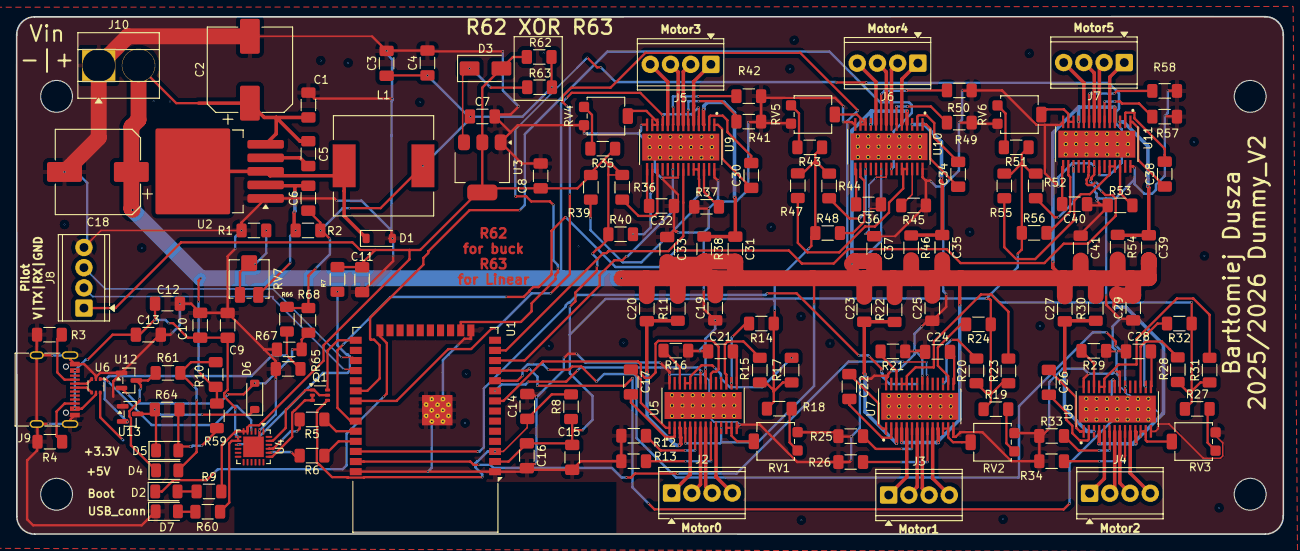
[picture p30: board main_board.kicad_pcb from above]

Board: 2 copper layers, 159.2 x 65.0 mm, 147 parts (0 on the bottom side), 144 nets.

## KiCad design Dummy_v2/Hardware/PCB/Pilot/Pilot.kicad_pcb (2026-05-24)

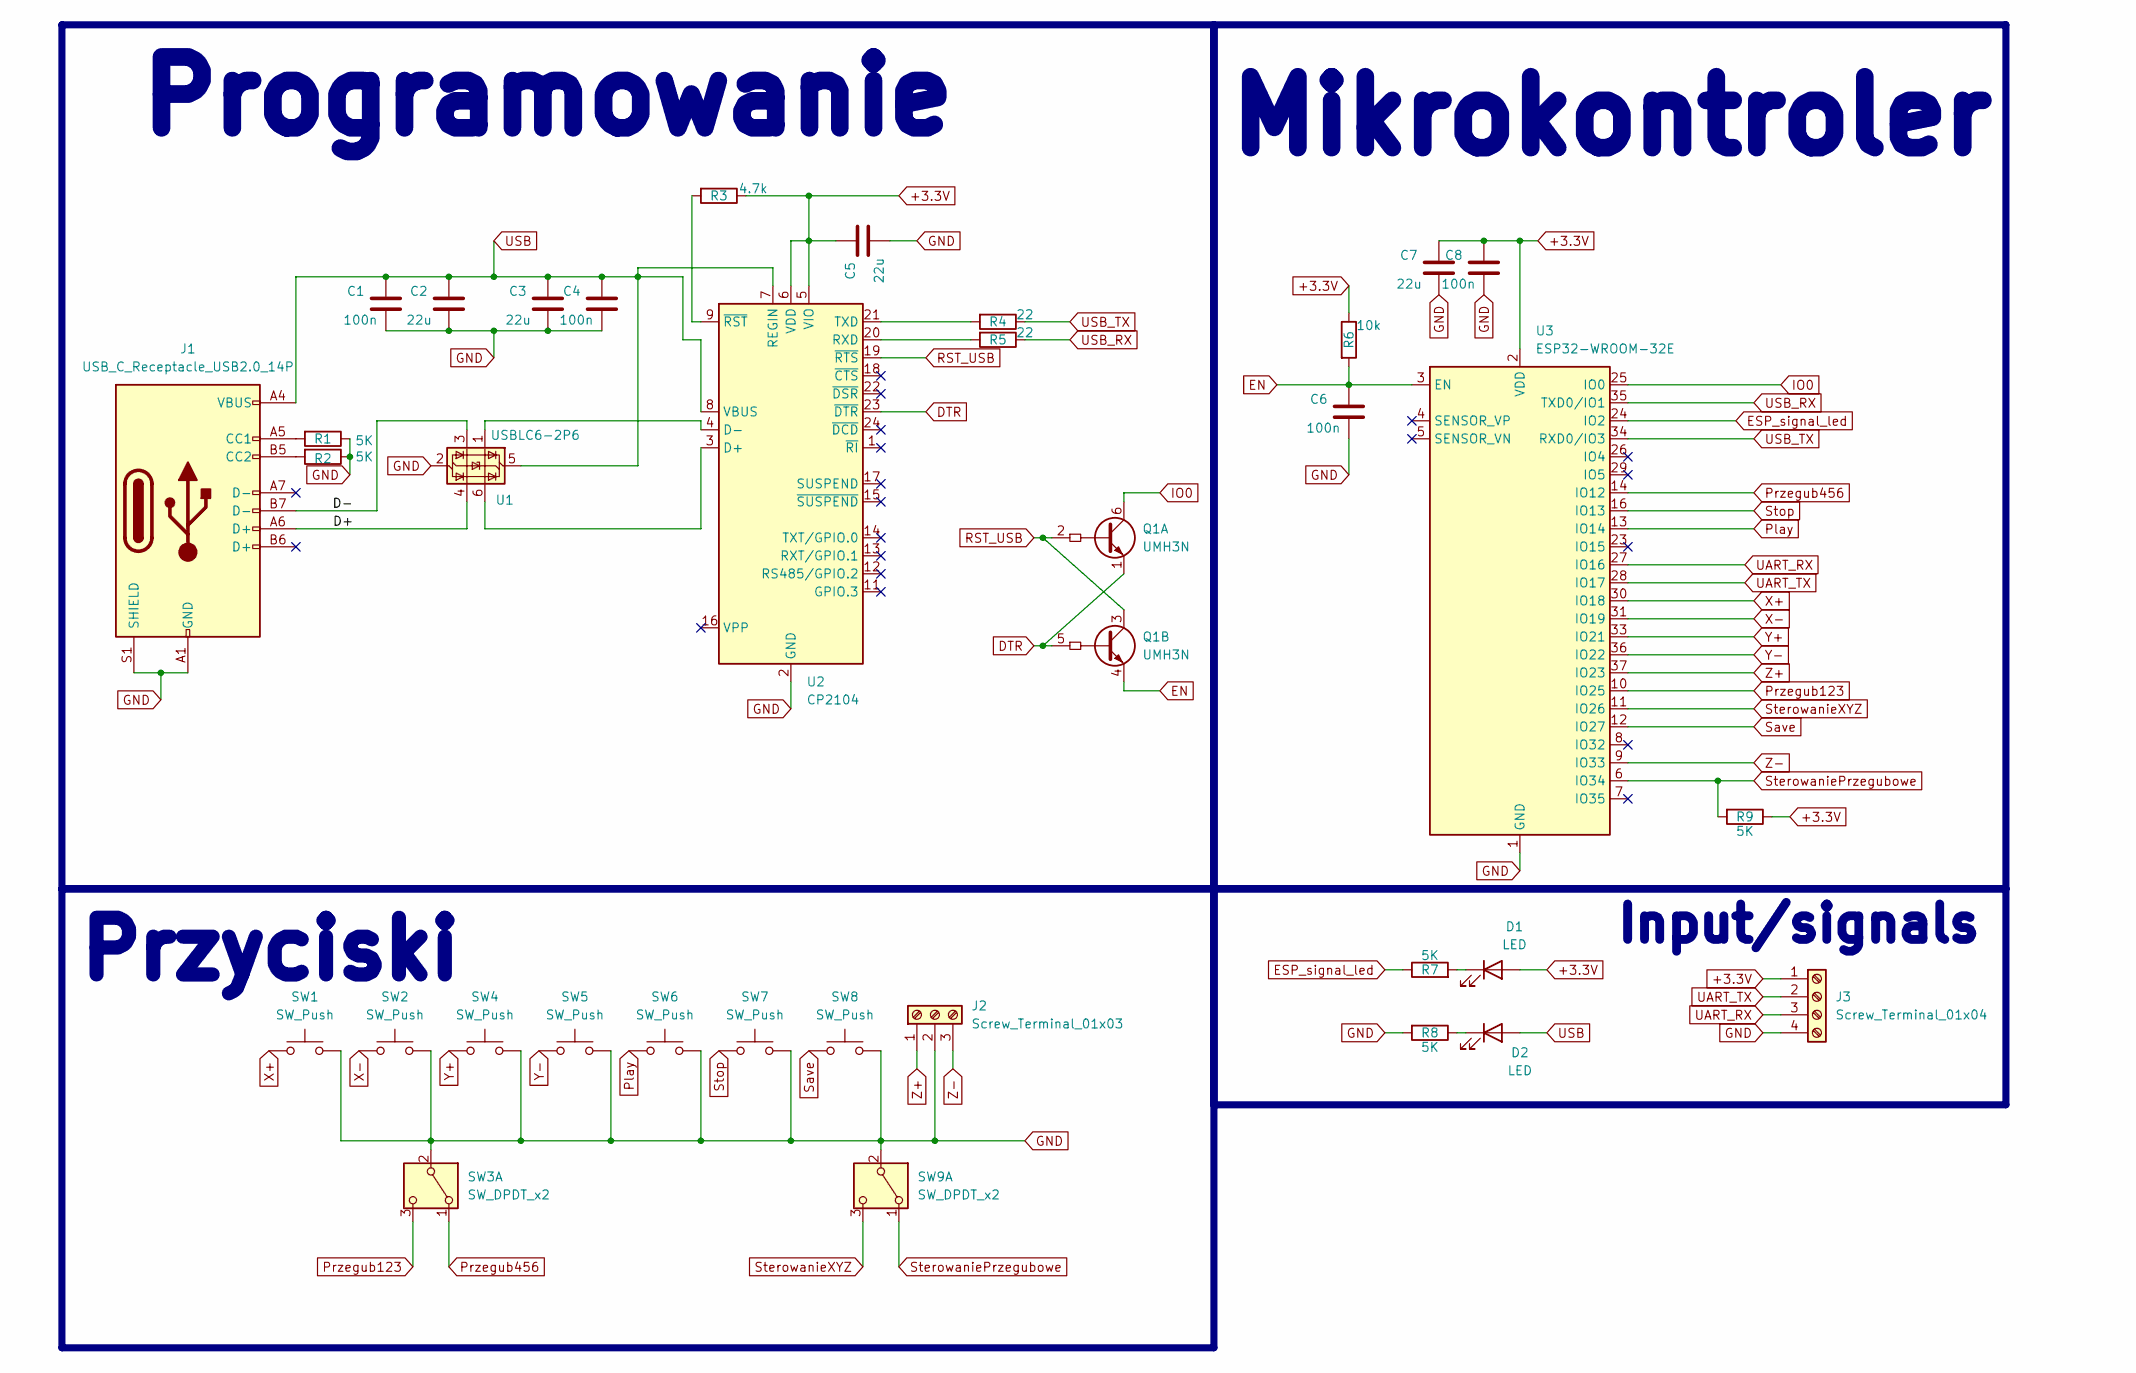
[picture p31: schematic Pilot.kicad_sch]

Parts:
C1, C4, C6, C8: 100n; C_1206_3216Metric_Pad1.33x1.80mm_HandSolder
C2, C3, C5, C7: 22u; C_1206_3216Metric_Pad1.33x1.80mm_HandSolder
D1, D2: LED; LED_1206_3216Metric
J1: USB_C_Receptacle_USB2.0_14P; USB_C_Receptacle_GCT_USB4105-xx-A_16P_TopMnt_Horizontal
J2: Screw_Terminal_01x03; TerminalBlock_MaiXu_MX126-5.0-03P_1x03_P5.00mm
J3: Screw_Terminal_01x04; TerminalBlock_MaiXu_MX126-5.0-04P_1x04_P5.00mm
Q1: UMH3N; SOT-363_SC-70-6
R1, R2, R7, R8, R9: 5K; R_1206_3216Metric_Pad1.30x1.75mm_HandSolder
R3: 4.7k; R_1206_3216Metric_Pad1.30x1.75mm_HandSolder
R4, R5: 22; R_1206_3216Metric_Pad1.30x1.75mm_HandSolder
R6: 10k; R_1206_3216Metric_Pad1.30x1.75mm_HandSolder
SW1, SW2, SW4, SW5, SW6, SW7, SW8: SW_Push; SW_Push_1P1T_NO_CK_KSC6xxJ
SW3, SW9: SW_DPDT_x2; SW_CK_JS202011CQN_DPDT_Straight
U1: USBLC6-2P6; SOT-666
U2: CP2104; QFN-24-1EP_4x4mm_P0.5mm_EP2.6x2.6mm
U3: ESP32-WROOM-32E; ESP32-WROOM-32D

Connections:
+3.3V: C5.1, C7.1, C8.1, D1.2 (A), J3.1, R3.1, R6.1, R9.1, U2.5 (VIO), U2.6 (VDD), U3.2 (VDD)
/D+: J1.A6 (D+), U1.4 (I/O2)
/D-: J1.B7 (D-), U1.3 (I/O2)
DTR: Q1.1 (E1), Q1.5 (B2), U2.23 (~DTR)
EN: C6.1, Q1.4 (E2), R6.2, U3.3 (EN)
ESP_signal_led: R7.1, U3.24 (IO2)
GND: C1.2, C2.2, C3.2, C4.2, C5.2, C6.2, C7.2, C8.2, J1.A1 (GND), J1.A12 (GND), J1.B1 (GND), J1.B12 (GND), J1.S1 (SHIELD), J2.2, J3.4, R1.1, R2.1, R8.2, SW1.2, SW2.2, SW3.2 (B), SW4.2, SW5.2, SW6.2, SW7.2, SW8.2, SW9.2 (B), U1.2 (GND), U2.2 (GND), U2.25 (GND), U3.1 (GND), U3.15 (GND), U3.38 (GND), U3.39 (GND)
IO0: Q1.6 (C1), U3.25 (IO0)
unnamed: D1.1 (K), R7.2
unnamed: D2.1 (K), R8.1
unnamed: J1.A5 (CC1), R1.2
unnamed: J1.B5 (CC2), R2.2
unnamed: U1.6 (I/O1), U2.3 (D+)
unnamed: U1.1 (I/O1), U2.4 (D-)
unnamed: R5.2, U2.20 (RXD)
unnamed: R4.2, U2.21 (TXD)
unnamed: R3.2, U2.9 (~RST)
Play: SW6.1, U3.13 (IO14)
Przegub123: SW3.3 (C), U3.10 (IO25)
Przegub456: SW3.1 (A), U3.14 (IO12)
RST_USB: Q1.2 (B1), Q1.3 (C2), U2.19 (~RTS)
Save: SW8.1, U3.12 (IO27)
SterowaniePrzegubowe: R9.2, SW9.1 (A), U3.6 (IO34)
SterowanieXYZ: SW9.3 (C), U3.11 (IO26)
Stop: SW7.1, U3.16 (IO13)
UART_RX: J3.3, U3.27 (IO16)
UART_TX: J3.2, U3.28 (IO17)
USB: C1.1, C2.1, C3.1, C4.1, D2.2 (A), J1.A4 (VBUS), J1.A9 (VBUS), J1.B4 (VBUS), J1.B9 (VBUS), U1.5 (VBUS), U2.7 (REGIN), U2.8 (VBUS)
USB_RX: R5.1, U3.35 (TXD0/IO1)
USB_TX: R4.1, U3.34 (RXD0/IO3)
X+: SW1.1, U3.30 (IO18)
X-: SW2.1, U3.31 (IO19)
Y+: SW4.1, U3.33 (IO21)
Y-: SW5.1, U3.36 (IO22)
Z+: J2.1, U3.37 (IO23)
Z-: J2.3, U3.9 (IO33)

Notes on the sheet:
Przyciski
Programowanie
Input/signals
Mikrokontroler

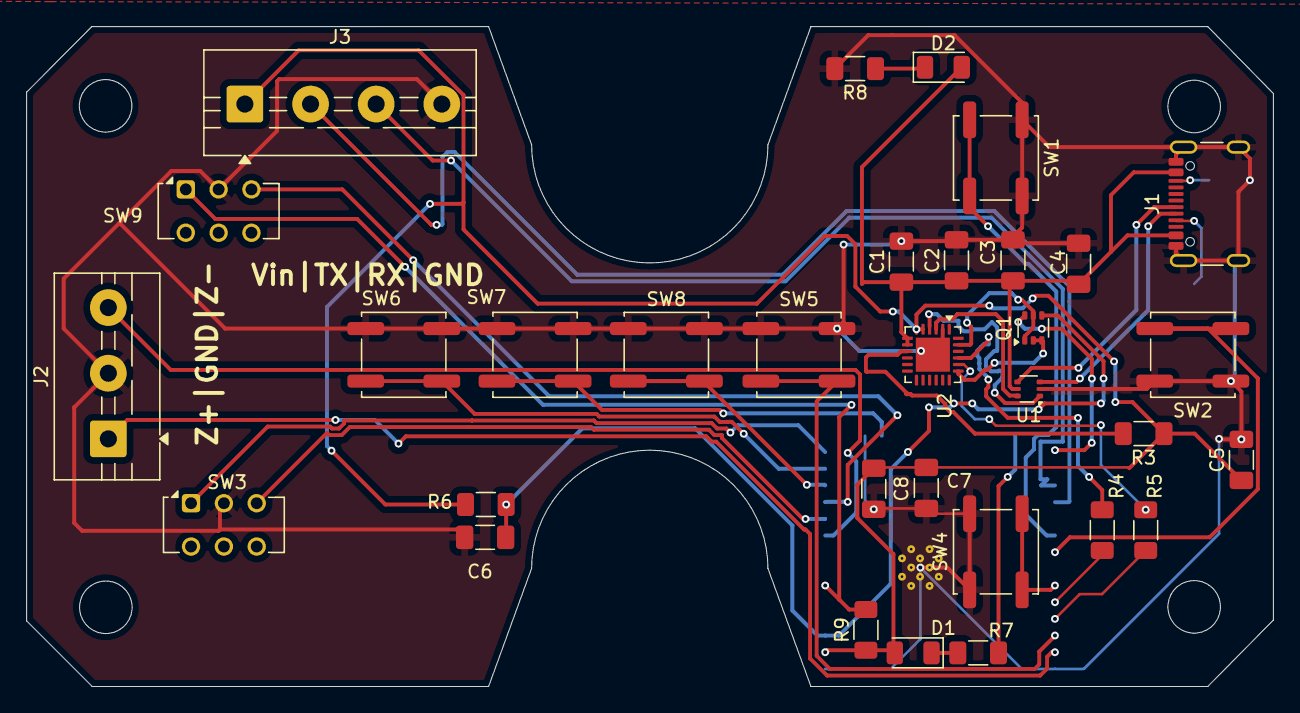
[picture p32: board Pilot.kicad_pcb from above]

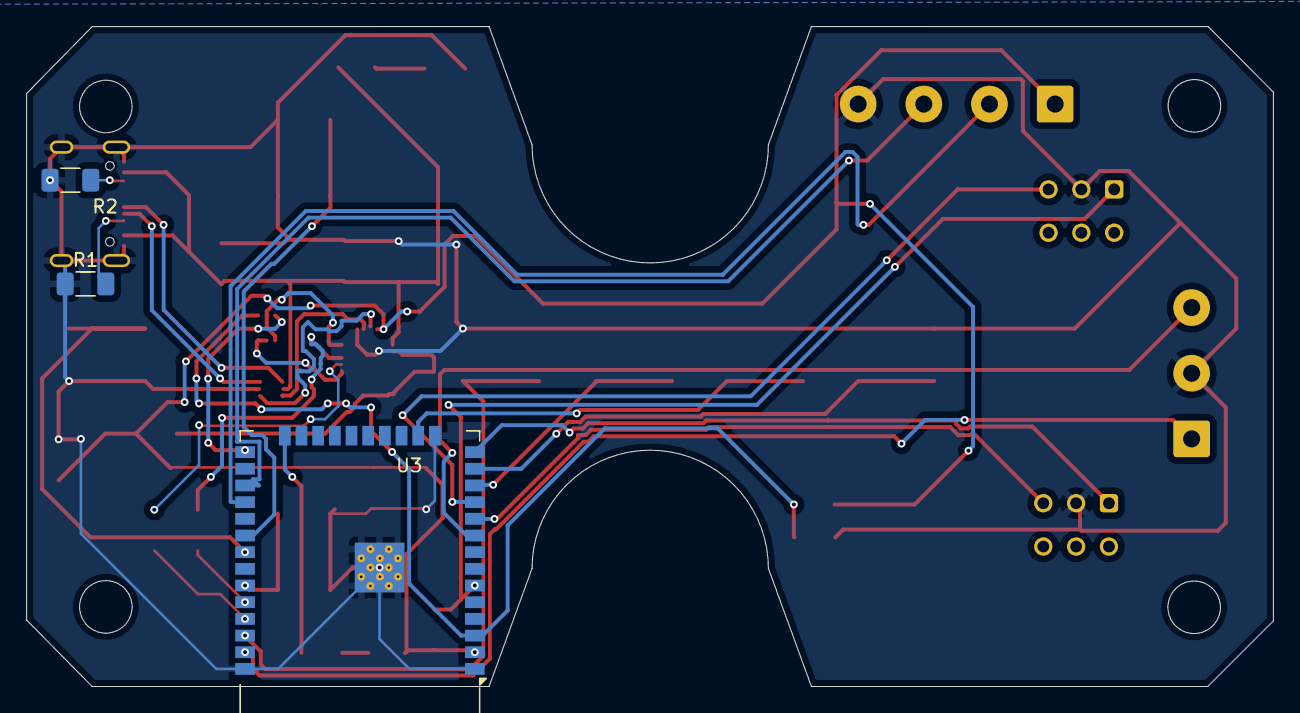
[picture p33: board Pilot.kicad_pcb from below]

Board: 2 copper layers, 95.0 x 50.3 mm, 35 parts (3 on the bottom side), 36 nets.

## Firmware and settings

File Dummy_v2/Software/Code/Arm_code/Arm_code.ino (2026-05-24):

#include <Arduino.h>
#include <AccelStepper.h>
#include <WiFi.h>
#include <WebServer.h>

// ===== Ustawienia Access Pointa =====
const char* ap_ssid = "Dummy_remote";   // nazwa sieci
const char* ap_pass = "123456789";      // hasło (min. 8 znaków)

// ===== Serwer HTTP =====
WebServer server(80);

// ---------- PARAMETRY ----------
#define NUM_STEPPERS        6
#define STEPS_PER_REV       200
#define MICROSTEPS          16
#define STEP_CM             0.5f     // krok kartezjański na klik
#define STEP_DEG            1.0f     // krok kątowy na klik
#define EPS_STEPS           3        // tolerancja do "celu"
#define Arm_length          18.0f    // długość ramion

// Stałe pomocnicze do kinematyki
#define DEG2RAD (PI/180.0f)
#define RAD2DEG (180.0f/PI)

// Przyjęte wymiary "narzędzia" (offset od środka nadgarstka do końcówki)
#define TOOL_X 0.0f
#define TOOL_Y 0.0f
#define TOOL_Z 0.0f

// Fragment tabeli D–H używany tylko do wyznaczenia R0_3 (orientacja)
// n  θ_off  d    a           α
// 1   0     d1   0           90
// 2   90    0    a2=Arm_len  0
// 3   0     0    0           90
static const float DH_d[3]            = { 10.0f,      0.0f,       0.0f };
static const float DH_a[3]            = { 0.0f,      Arm_length, 0.0f };
static const float DH_alpha_deg[3]    = { 90.0f,     0.0f,       90.0f };
static const float DH_theta_off_deg[3]= { 0.0f,      90.0f,      0.0f };

// UART (pilot)
#define UART_RX 16
#define UART_TX 17
HardwareSerial& LINK = Serial2;
static const uint32_t BAUD = 9600;

// LED
#define LED_PIN 2

// PINY DRV
#define STEP_PIN0 33
#define DIR_PIN0  32
#define STEP_PIN1 22
#define DIR_PIN1  23
#define STEP_PIN2 26
#define DIR_PIN2  25
#define STEP_PIN3 14
#define DIR_PIN3  27
#define STEP_PIN4 18
#define DIR_PIN4  19
#define STEP_PIN5 13
#define DIR_PIN5  21

const int STEP_PINS[NUM_STEPPERS] = { STEP_PIN0, STEP_PIN1, STEP_PIN2, STEP_PIN3, STEP_PIN4, STEP_PIN5 };
const int DIR_PINS [NUM_STEPPERS] = { DIR_PIN0,  DIR_PIN1,  DIR_PIN2,  DIR_PIN3,  DIR_PIN4,  DIR_PIN5  };

// Przełożenia: obr./silnika na obr./przegubu
const float GEAR[NUM_STEPPERS] = { 6.0f, 6.0f, 4.0f, 2.0f, 2.0f, 1.0f };
// Polaryzacje DIR (+1 normalnie, -1 odwróć)
const int   DIR_SIGN[NUM_STEPPERS] = { -1, -1, +1, -1, +1, -1 };

AccelStepper* M[NUM_STEPPERS] = { nullptr };
float MAX_V[NUM_STEPPERS];     // [steps/s]
float MAX_A[NUM_STEPPERS];     // [steps/s^2]

// ===== Zmienne na współrzędne z WWW =====
float X_val = 18.0f;
float Y_val = 0.0f;
float Z_val = 18.0f;
float A_val =270.0f;  // Roll
float K_val = 90.0f;  // Pitch (Pich)
float W_val = 90.0f;  // Yaw

bool newCmd6DOF = false;      // flaga nowej komendy z telefonu
bool cmdF1 = false;
bool cmdF2 = false;
bool cmdF3 = false;
bool cmdF4 = false;

// ---------- STAN / TRYBY ----------
enum { MODE_XYZ = 0, MODE_JOINTS = 1 };
enum { GROUP_13 = 0, GROUP_46 = 1 };
int MODE  = MODE_XYZ;   // domyślnie XYZ
int GROUP = GROUP_13;   // domyślnie 1-3

// Pozycja celu w XYZ (ostatni punkt)
float GOAL_X = 18.0f, GOAL_Y = 0.0f, GOAL_Z = 18.0f;

// Kąty referencyjne dla (18,0,18)
bool  REF_SET = false;
float REF_K = 0.0f, REF_A = 0.0f, REF_B = 0.0f;

// Aktualny "target" kroków dla wszystkich osi
long TARGET_STEPS[NUM_STEPPERS] = {0};

// ---------- PROSTE NARZĘDZIA ----------
static float Klamra_tryg_ochronna(float v){
  if(v<-1.f) return -1.f;
  if(v>1.f)  return  1.f;
  return v;
}

static float Zwin_do_180(float a){
  while(a<=-180.f)a+=360.f;
  while(a>180.f)a-=360.f;
  return a;
}

static void Klamra_max_zasieg(float &x, float &y, float &z){
  const float rMax = 2.0f * Arm_length - 0.5f;
  float r = sqrtf(x*x + y*y + z*z);

  if (r > rMax && r > 0.0f) {
    float s = rMax / r;
    x *= s;
    y *= s;
    z *= s;
  }
}


static long Steps_for_deg(int Gear_i, float deg){
  float turns = deg / 360.0f;
  float motorTurns = turns * GEAR[Gear_i];
  float steps = motorTurns * STEPS_PER_REV * MICROSTEPS;
  return lroundf(steps);
}

static void Invers_kinematic(float x, float y, float z, float &K, float &A, float &B){
  float rxy = hypotf(x, y);
  float d   = hypotf(rxy, z);
  float s   = Klamra_tryg_ochronna(d / (2.0f*Arm_length));
  float elev  = atan2f(z, rxy) * 180.0f/PI;
  float delta = acosf(s)       * 180.0f/PI;
  A = elev + delta;                 // ~90° w (18,0,18)
  B = 2.0f * asinf(s) * 180.0f/PI;  // ~90° w (18,0,18)
  K = atan2f(y, x) * 180.0f/PI;
  if (K < 0) K += 360.0f;
}

// ---------- MACIERZE / RPY / D-H (prosto) ----------

// 4x4 z parametrów D–H (θ,d,a,α) – θ i α w stopniach
static void DH_mat(float theta_deg, float d, float a, float alpha_deg, float T[4][4]){
  float th = theta_deg * DEG2RAD;
  float al = alpha_deg * DEG2RAD;

  float cth = cosf(th);
  float sth = sinf(th);
  float cal = cosf(al);
  float sal = sinf(al);

  T[0][0] = cth;
  T[0][1] = -sth*cal;
  T[0][2] =  sth*sal;
  T[0][3] =  a*cth;

  T[1][0] = sth;
  T[1][1] = cth*cal;
  T[1][2] = -cth*sal;
  T[1][3] =  a*sth;

  T[2][0] = 0.0f;
  T[2][1] = sal;
  T[2][2] = cal;
  T[2][3] = d;

  T[3][0] = 0.0f;
  T[3][1] = 0.0f;
  T[3][2] = 0.0f;
  T[3][3] = 1.0f;
}

// mnożenie macierzy 4x4: C = A*B
static void Mat4_mul(const float A[4][4], const float B[4][4], float C[4][4]){
  for(int i=0;i<4;i++){
    for(int j=0;j<4;j++){
      float s = 0.0f;
      for(int k=0;k<4;k++) s += A[i][k]*B[k][j];
      C[i][j] = s;
    }
  }
}

// wyciągnięcie macierzy 3x3 z 4x4 (górny lewy róg)
static void Mat3_from_4x4(const float T[4][4], float R[3][3]){
  for(int i=0;i<3;i++)
    for(int j=0;j<3;j++)
      R[i][j] = T[i][j];
}

// transpozycja 3x3
static void Mat3_transpose(const float A[3][3], float AT[3][3]){
  for(int i=0;i<3;i++)
    for(int j=0;j<3;j++)
      AT[i][j] = A[j][i];
}

// mnożenie 3x3: C = A*B
static void Mat3_mul(const float A[3][3], const float B[3][3], float C[3][3]){
  for(int i=0;i<3;i++){
    for(int j=0;j<3;j++){
      float s = 0.0f;
      for(int k=0;k<3;k++) s += A[i][k]*B[k][j];
      C[i][j] = s;
    }
  }
}

// RPY (Z–Y–X, yaw–pitch–roll) -> macierz R
static void RPY_to_R(float phi_deg, float theta_deg, float psi_deg, float R[3][3]){
  float phi   = phi_deg   * DEG2RAD; // roll  (X)
  float theta = theta_deg * DEG2RAD; // pitch (Y)
  float psi   = psi_deg   * DEG2RAD; // yaw   (Z)

  float cphi = cosf(phi),  sphi = sinf(phi);
  float cth  = cosf(theta),sth  = sinf(theta);
  float cpsi = cosf(psi),  spsi = sinf(psi);

  R[0][0] =  cpsi*cth;
  R[0][1] =  cpsi*sth*sphi - spsi*cphi;
  R[0][2] =  cpsi*sth*cphi + spsi*sphi;

  R[1][0] =  spsi*cth;
  R[1][1] =  spsi*sth*sphi + cpsi*cphi;
  R[1][2] =  spsi*sth*cphi - cpsi*sphi;

  R[2][0] = -sth;
  R[2][1] =  cth*sphi;
  R[2][2] =  cth*cphi;
}

// R -> RPY (Z–Y–X)
static void RPY_from_R(const float R[3][3], float &phi_deg, float &theta_deg, float &psi_deg){
  float r11 = R[0][0];
  float r21 = R[1][0];
  float r31 = R[2][0];
  float r32 = R[2][1];
  float r33 = R[2][2];

  float theta = -asinf(Klamra_tryg_ochronna(r31));
  float phi   = atan2f(r32, r33);
  float psi   = atan2f(r21, r11);

  phi_deg   = phi   * RAD2DEG;
  theta_deg = theta * RAD2DEG;
  psi_deg   = psi   * RAD2DEG;
}

// R0_3 z kątów K,A,B + tabeli D–H (tylko orientacja)
static void R03_from_KAB(float K_deg, float A_deg, float B_deg, float R0_3[3][3]){
  float T01[4][4], T12[4][4], T23[4][4];
  float T02[4][4], T03[4][4];

  float th1 = K_deg + DH_theta_off_deg[0];
  float th2 = A_deg + DH_theta_off_deg[1];
  float th3 = B_deg + DH_theta_off_deg[2];

  DH_mat(th1, DH_d[0], DH_a[0], DH_alpha_deg[0], T01);
  DH_mat(th2, DH_d[1], DH_a[1], DH_alpha_deg[1], T12);
  DH_mat(th3, DH_d[2], DH_a[2], DH_alpha_deg[2], T23);

  Mat4_mul(T01, T12, T02);
  Mat4_mul(T02, T23, T03);

  Mat3_from_4x4(T03, R0_3);
}

// ---------- STRONA GŁÓWNA ----------
void handleRoot() {
  String page = "";
  page += "<!DOCTYPE html><html><head>";
  page += "<meta charset='UTF-8'>";
  page += "<meta name='viewport' content='width=device-width, initial-scale=1'>";
  page += "<title>Dummy remote pilot</title>";
  page += "<style>";
  page += "html { font-family: Helvetica; text-align: center; }";
  page += "body { margin-top: 40px; }";
  page += "label { display: block; margin: 8px; }";
  page += "input { padding: 5px; width: 140px; }";
  page += ".button { background-color: #4CAF50; color: white; border: none;";
  page += "padding: 10px 20px; font-size: 16px; cursor: pointer; margin-top:15px; }";
  page += "</style></head><body>";

  page += "<h1>Dummy remote pilot</h1>";
  page += "<h3>Podaj współrzędne 6DOF</h3>";

  page += "<form action='/set' method='GET'>";
  page += "<label>X    = <input type='number' step='0.01' name='X' value='" + String(X_val, 2) + "'></label>";
  page += "<label>Y    = <input type='number' step='0.01' name='Y' value='" + String(Y_val, 2) + "'></label>";
  page += "<label>Z    = <input type='number' step='0.01' name='Z' value='" + String(Z_val, 2) + "'></label>";
  page += "<label>Roll = <input type='number' step='0.01' name='Roll' value='" + String(A_val, 2) + "'></label>";
  page += "<label>Pich = <input type='number' step='0.01' name='Pich' value='" + String(K_val, 2) + "'></label>";
  page += "<label>Yaw  = <input type='number' step='0.01' name='Yaw' value='" + String(W_val, 2) + "'></label>";

  // Twoje istniejące przyciski
  page += "<input class='button' type='submit' name='action' value='Wyślij'>";
  page += "<input class='button' type='submit' name='action' value='save'>";
  page += "<input class='button' type='submit' name='action' value='play'>";

  // ---- NOWE 4 PRZYCISKI ----
  // Używam <button>, żeby tekst na przycisku mógł być ładny,
  // a value (action) krótkie i stabilne w kodzie.
  page += "<br>";
  page += "<button class='button' type='submit' name='action' value='f1'>Linia prosta</button>";
  page += "<button class='button' type='submit' name='action' value='f2'>Linia krzywa</button>";
  page += "<button class='button' type='submit' name='action' value='f3'>okrag</button>";
  page += "<button class='button' type='submit' name='action' value='f4'>chwyt</button>";

  page += "</form>";

  page += "<h3>Aktualne wartości na ESP32:</h3>";
  page += "X = " + String(X_val, 2) + "<br>";
  page += "Y = " + String(Y_val, 2) + "<br>";
  page += "Z = " + String(Z_val, 2) + "<br>";
  page += "Roll = " + String(A_val, 2) + "<br>";
  page += "Pich = " + String(K_val, 2) + "<br>";
  page += "Yaw = " + String(W_val, 2) + "<br>";

  page += "</body></html>";

  server.send(200, "text/html", page);
}

void handleSet() {
  // Zaczytanie wartości z formularza (tak jak było)
  if (server.hasArg("X"))    X_val = server.arg("X").toFloat();
  if (server.hasArg("Y"))    Y_val = server.arg("Y").toFloat();
  if (server.hasArg("Z"))    Z_val = server.arg("Z").toFloat();
  if (server.hasArg("Roll")) A_val = server.arg("Roll").toFloat();
  if (server.hasArg("Pich")) K_val = server.arg("Pich").toFloat();
  if (server.hasArg("Yaw"))  W_val = server.arg("Yaw").toFloat();

  Serial.println("Nowe współrzędne (z WWW):");
  Serial.print("X=");    Serial.println(X_val);
  Serial.print("Y=");    Serial.println(Y_val);
  Serial.print("Z=");    Serial.println(Z_val);
  Serial.print("Roll="); Serial.println(A_val);
  Serial.print("Pich="); Serial.println(K_val);
  Serial.print("Yaw=");  Serial.println(W_val);

  String action = "Wyślij";
  if (server.hasArg("action")) {
    action = server.arg("action");
  }

  if (action == "save") {
    Serial.println("save z WWW");
    Save();
  }
  else if (action == "play") {
    Serial.println("play z WWW");
    Play();
  }
  // ---- NOWE AKCJE ----
  else if (action == "f1") {
    Serial.println("f1 z WWW");
    cmdF1 = true;   // w dalszej części kodu zrobisz if(cmdF1){...}
  }
  else if (action == "f2") {
    Serial.println("f2 z WWW");
    cmdF2 = true;
  }
  else if (action == "f3") {
    Serial.println("f3 z WWW");
    cmdF3 = true;
  }
  else if (action == "f4") {
    Serial.println("f4 z WWW");
    cmdF4 = true;
  }
  else { // "Wyślij" lub cokolwiek innego
    newCmd6DOF = true;
  }

  handleRoot();
}


// ---------- FUNKCJA 6DOF ----------
static void Move_6DOF(float x, float y, float z,
                      float phi, float theta, float psi)
{
  float x_wc = x - TOOL_X;
  float y_wc = y - TOOL_Y;
  float z_wc = z - TOOL_Z;

  Klamra_max_zasieg(x_wc, y_wc, z_wc);

  float K, A, B;
  Invers_kinematic(x_wc, y_wc, z_wc, K, A, B);

  if (!REF_SET){
    REF_K = K; REF_A = A; REF_B = B;
    REF_SET = true;
  }

  float dK = Zwin_do_180(K - REF_K);
  float dA = Zwin_do_180(A - REF_A);
  float dB = Zwin_do_180(B - REF_B);

  long t[NUM_STEPPERS];
  t[0] = Steps_for_deg(0, dK);
  t[1] = Steps_for_deg(1, dA);
  t[2] = Steps_for_deg(2, dB);

  float R0_3[3][3];
  R03_from_KAB(K, A, B, R0_3);

  float R0_6[3][3];
  RPY_to_R(phi, theta, psi, R0_6);

  float R3_0[3][3];
  float R3_6[3][3];
  Mat3_transpose(R0_3, R3_0);
  Mat3_mul(R3_0, R0_6, R3_6);

  float phi_w, theta_w, psi_w;
  RPY_from_R(R3_6, phi_w, theta_w, psi_w);

  t[3] = Steps_for_deg(3, phi_w);
  t[4] = Steps_for_deg(4, theta_w);
  t[5] = Steps_for_deg(5, psi_w);

  for(int i=0;i<NUM_STEPPERS;i++){
    M[i]->moveTo(t[i]);
    TARGET_STEPS[i] = t[i];
  }

  Same_time();

  GOAL_X = x;
  GOAL_Y = y;
  GOAL_Z = z;
}

// ---------- Ustaw limity prędkości/acc ----------tancie
static void Ustaw_parametry_silnikow(float deg_per_s, float deg_per_s2){
  for(int i=0;i<NUM_STEPPERS;i++){
    float stepsPerDeg = (STEPS_PER_REV * MICROSTEPS * GEAR[i]) / 360.0f;
    MAX_V[i] = stepsPerDeg * deg_per_s;
    MAX_A[i] = stepsPerDeg * deg_per_s2;
    M[i]->setMaxSpeed(MAX_V[i]);
    M[i]->setAcceleration(MAX_A[i]);
  }
}

//skaluje predkosci silników wzgledem najdłużej trasy
static void Same_time(){
  float tMin = 0.0f;
  long d[NUM_STEPPERS];
  for(int i=0;i<NUM_STEPPERS;i++){
    d[i] = abs(M[i]->distanceToGo());
    if (d[i] > 0) {
      float t = d[i] / MAX_V[i];
      if (t > tMin) tMin = t;
    }
  }
  if (tMin <= 0.0f) return;
  for(int i=0;i<NUM_STEPPERS;i++){
    if (d[i] == 0) continue;
    float v = d[i] / tMin; if (v > MAX_V[i]) v = MAX_V[i];
    M[i]->setMaxSpeed(v);
    float a = MAX_A[i] * (v / MAX_V[i]); if (a < 100.0f) a = 100.0f;
    M[i]->setAcceleration(a);
  }
}

// Czy wszystkie osie są "na celu"
static bool Na_celu(){
  for(int i=0;i<NUM_STEPPERS;i++){
    if (abs(M[i]->distanceToGo()) > EPS_STEPS) return false;
  }
  return true;
}

// ---------- QUEUE XYZ (prosto) ----------
#define Queue_limit 256
float QX[Queue_limit], QY[Queue_limit], QZ[Queue_limit];
int QH=0, QT=0, QC=0;
static void Queue_xyz_Clear(){ QH=QT=QC=0; }
static bool Queue_xyz_Push(float x,float y,float z){
  if (QC>=Queue_limit) return false;
  QX[QT]=x; QY[QT]=y; QZ[QT]=z;
  QT=(QT+1)%Queue_limit; QC++; return true;
}
static bool Queue_xyz_pop(float &x,float &y,float &z){
  if (QC==0) return false;
  x=QX[QH]; y=QY[QH]; z=QZ[QH];
  QH=(QH+1)%Queue_limit; QC--; return true;
}
static void Queue_xyz_goal(float &x,float &y,float &z){
  if (QC==0){ x=GOAL_X; y=GOAL_Y; z=GOAL_Z; return; }
  int idx = (QT+Queue_limit-1)%Queue_limit;
  x=QX[idx]; y=QY[idx]; z=QZ[idx];
}

// ---------- QUEUE JOINTS (pełne wektory kroków) ----------
long JQ[Queue_limit][NUM_STEPPERS];
int  JH=0, JT=0, JC=0;
static void Queue_jq_clear(){ JH=JT=JC=0; }
static bool Queue_jq_push(long vec[NUM_STEPPERS]){
  if (JC>=Queue_limit) return false;
  for(int i=0;i<NUM_STEPPERS;i++) JQ[JT][i]=vec[i];
  JT=(JT+1)%Queue_limit; JC++; return true;
}
static bool Queue_jq_pop(long vec[NUM_STEPPERS]){
  if (JC==0) return false;
  for(int i=0;i<NUM_STEPPERS;i++) vec[i]=JQ[JH][i];
  JH=(JH+1)%Queue_limit; JC--; return true;
}
static void Queue_jq_current(long vec[NUM_STEPPERS]){
  if (JC==0){
    for(int i=0;i<NUM_STEPPERS;i++) vec[i]=TARGET_STEPS[i];
    return;
  }
  int idx = (JT+Queue_limit-1)%Queue_limit;
  for(int i=0;i<NUM_STEPPERS;i++) vec[i]=JQ[idx][i];
}

// ---------- PROGRAM (Save/Play) ----------
enum { PROG_EMPTY=0, PROG_XYZ=1, PROG_JOINTS=2 };
#define PROG_LIMIT 256
int   PROG_KIND = PROG_EMPTY;
int   PROG_COUNT = 0;
float PX[PROG_LIMIT], PY[PROG_LIMIT], PZ[PROG_LIMIT];          // XYZ
long  Prog_step[PROG_LIMIT][NUM_STEPPERS];                     // JOINTS

static void prog_clear(){ PROG_KIND=PROG_EMPTY; PROG_COUNT=0; }
static bool prog_add_xyz(float x,float y,float z){
  if (PROG_COUNT>=PROG_LIMIT) return false;
  if (PROG_KIND==PROG_JOINTS){ prog_clear(); }
  PROG_KIND=PROG_XYZ;
  PX[PROG_COUNT]=x; PY[PROG_COUNT]=y; PZ[PROG_COUNT]=z; PROG_COUNT++;
  return true;
}
static bool prog_add_joints(const long vec[NUM_STEPPERS]){
  if (PROG_COUNT>=PROG_LIMIT) return false;
  if (PROG_KIND==PROG_XYZ){ prog_clear(); }
  PROG_KIND=PROG_JOINTS;
  for(int i=0;i<NUM_STEPPERS;i++) Prog_step[PROG_COUNT][i]=vec[i];
  PROG_COUNT++;
  return true;
}

// ---------- LOGIKA XYZ ----------
static void Move_to_xyz(float x,float y,float z){
  Klamra_max_zasieg(x,y,z);
  float K,A,B; Invers_kinematic(x,y,z,K,A,B);
  if (!REF_SET){
    REF_K=K; REF_A=A; REF_B=B; REF_SET=true;
  }

  float dK = Zwin_do_180(K-REF_K);
  float dA = Zwin_do_180(A-REF_A);
  float dB = Zwin_do_180(B-REF_B);

  long t0 = Steps_for_deg(0,dK);
  long t1 = Steps_for_deg(1,dA);
  long t2 = Steps_for_deg(2,dB);

  M[0]->moveTo(t0); TARGET_STEPS[0]=t0;
  M[1]->moveTo(t1); TARGET_STEPS[1]=t1;
  M[2]->moveTo(t2); TARGET_STEPS[2]=t2;

  for(int i=3;i<NUM_STEPPERS;i++){
    M[i]->moveTo(TARGET_STEPS[i]);
  }

  Same_time();
  GOAL_X=x; GOAL_Y=y; GOAL_Z=z;
}

static void Next_xyz(){
  if (!Na_celu()) return;
  float nx,ny,nz;
  if (Queue_xyz_pop(nx,ny,nz)) Move_to_xyz(nx,ny,nz);
}

// ---------- LOGIKA PRZEGUBÓW ----------
static void Move_to_joints(const long vec[NUM_STEPPERS]){
  for(int i=0;i<NUM_STEPPERS;i++){
    M[i]->moveTo(vec[i]);
    TARGET_STEPS[i]=vec[i];
  }
  Same_time();
}

static void Queue_joints_move(int joint, float deltaDeg){
  long base[NUM_STEPPERS]; Queue_jq_current(base);
  base[joint] += Steps_for_deg(joint, deltaDeg);
  if (Queue_jq_push(base) && Na_celu()){
    long first[NUM_STEPPERS];
    if (Queue_jq_pop(first)) Move_to_joints(first);
  }
}

static int map_axis(char axis){
  if (GROUP==GROUP_13){
    if (axis=='X') return 0;
    if (axis=='Y') return 1;
    return 2;
  } else {
    if (axis=='X') return 3;
    if (axis=='Y') return 4;
    return 5;
  }
}

static void Next_joint(){
  if (!Na_celu()) return;
  long nx[NUM_STEPPERS];
  if (Queue_jq_pop(nx)) Move_to_joints(nx);
}

// ---------- KOMENDY WYSOKIEGO POZIOMU ----------
static uint32_t lastStopMs=0; static int stopClicks=0; const uint32_t STOP_MS=1500;

static void Save(){
  bool ok=false;
  if (MODE==MODE_XYZ){
    ok = prog_add_xyz(GOAL_X,GOAL_Y,GOAL_Z);
  } else {
    ok = prog_add_joints(TARGET_STEPS);
  }
  if (ok){
    digitalWrite(LED_PIN,HIGH);
    delay(20);
    digitalWrite(LED_PIN,LOW);
  }
}

static void Play(){
  if (PROG_COUNT==0 || PROG_KIND==PROG_EMPTY) {
    Serial.println(F("PLAY: empty")); return;
  }
  Queue_jq_clear(); Queue_xyz_Clear();
  if (PROG_KIND==PROG_XYZ){
    for(int i=0;i<PROG_COUNT;i++)
      Queue_xyz_Push(PX[i],PY[i],PZ[i]);
    if (Na_celu()) Next_xyz();
    Serial.print(F("PLAY XYZ, queued="));
    Serial.println(QC);
  } else {
    for(int i=0;i<PROG_COUNT;i++) {
      long v[NUM_STEPPERS];
      for(int j=0;j<NUM_STEPPERS;j++) v[j]=Prog_step[i][j];
      Queue_jq_push(v);
    }
    if (Na_celu()){
      long first[NUM_STEPPERS];
      if (Queue_jq_pop(first)) Move_to_joints(first);
    }
    Serial.print(F("PLAY JOINTS, queued="));
    Serial.println(JC);
  }
}
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
void loop(){
  server.handleClient();
    if (cmdF1) { cmdF1 = false; Prezentacja_linia_prosto(); }
    if (cmdF2) { cmdF2 = false; Prezentacja_linia_krzywo(); }
    if (cmdF3) { cmdF3 = false; Prezentacja_Okrag(); }
    if (cmdF4) { cmdF4 = false; Prezentacja_dlugi_ruch(); }

   //jeśli przyszła nowa komenda 6DOF z telefonu i ramię stoi -> wykonaj
  if (newCmd6DOF && Na_celu()) {
    Move_6DOF(X_val, Y_val, Z_val, A_val, K_val, W_val);
    newCmd6DOF = false;
  }

  for(int i=0;i<NUM_STEPPERS;i++) M[i]->run();
  Next_xyz();
  Next_joint();

  if (!LINK.available()) return;
  String line = LINK.readStringUntil('\n');
  line.trim();
  if (!line.startsWith("BTN:")) return;
  line.remove(0,4);

  if      (line=="Sterowanie_XYZ")        { setModeXYZ(); }
  else if (line=="Sterowanie_przegubowe") { setModeJoints(); }
  else if (line=="Przegub_13")            { setGroup13(); }
  else if (line=="Przegub_46")            { setGroup46(); }
  else if (line=="Save") { Save(); }
  else if (line=="Play") { Play(); }
  else if (line=="Stop") { Stop(); }
  else {
    if (MODE==MODE_XYZ){
      float bx,by,bz; Queue_xyz_goal(bx,by,bz);
      bool q=false;
      if      (line=="X+") q=Queue_xyz_Push(bx+STEP_CM, by,          bz);
      else if (line=="X-") q=Queue_xyz_Push(bx-STEP_CM, by,          bz);
      else if (line=="Y+") q=Queue_xyz_Push(bx,          by+STEP_CM, bz);
      else if (line=="Y-") q=Queue_xyz_Push(bx,          by-STEP_CM, bz);
      else if (line=="Z+") q=Queue_xyz_Push(bx,          by,          bz+STEP_CM);
      else if (line=="Z-") q=Queue_xyz_Push(bx,          by,          bz-STEP_CM);
      if (q && Na_celu()) Next_xyz();
    } else {
      int jx = map_axis('X');
      int jy = map_axis('Y');
      int jz = map_axis('Z');
      if      (line=="X+") Queue_joints_move(jx,+STEP_DEG);
      else if (line=="X-") Queue_joints_move(jx,-STEP_DEG);
      else if (line=="Y+") Queue_joints_move(jy,+STEP_DEG);
      else if (line=="Y-") Queue_joints_move(jy,-STEP_DEG);
      else if (line=="Z+") Queue_joints_move(jz,+STEP_DEG);
      else if (line=="Z-") Queue_joints_move(jz,-STEP_DEG);
    }
  }

  Serial.print(F("cmd: ")); Serial.print(line);
  Serial.print(F("  mode=")); Serial.print(MODE==MODE_XYZ?"XYZ":"JOINTS");
  Serial.print(F("  grp="));  Serial.print(GROUP==GROUP_13?"1-3":"4-6");
  Serial.print(F("  qXYZ=")); Serial.print(QC);
  Serial.print(F("  qJ="));   Serial.println(JC);
}

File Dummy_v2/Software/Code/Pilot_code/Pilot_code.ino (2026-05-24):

#include <Arduino.h>

// ===== UART2 (do urządzenia głównego) =====
#define UART_RX 16
#define UART_TX 17
HardwareSerial& LINK = Serial2;

// ===== Piny przycisków =====
const uint8_t BTN_PINS[] = {
  18,19,21,22,23,   // BTN1..BTN5
  32,33,25,26,27,   // BTN6..BTN10
  14,               // BTN11
  13,               // BTN12
  34                // BTN13 (zewn. pull-up do 3V3)
};

// true = INPUT_PULLUP, false = INPUT (dla GPIO34 tylko INPUT)
const bool USE_PULLUP[] = {
  1,1,1,1,1,
  1,1,1,1,1,
  1,
  1,
  0
};

const char* BTN_NAMES[] = {
  "Play","Przegub_46","Przegub_13","Sterowanie_przegubowe","Sterowanie_XYZ",
  "Save","Stop","Y-","X+","Y+",
  "X-","Z+","Z-"
};

// które przyciski mają reagować na przytrzymanie (auto-repeat)
const bool AUTO_REPEAT[] = {
  0,0,0,0,0,   // Play, przeguby, tryby
  0,0,         // Save, Stop
  1,1,1,       // Y-, X+, Y+
  1,1,1        // X-, Z+, Z-
};

static_assert(
  (sizeof(BTN_PINS) == sizeof(USE_PULLUP)) &&
  (sizeof(BTN_PINS)/sizeof(BTN_PINS[0]) == sizeof(BTN_NAMES)/sizeof(BTN_NAMES[0])) &&
  (sizeof(BTN_PINS)/sizeof(BTN_PINS[0]) == sizeof(AUTO_REPEAT)/sizeof(AUTO_REPEAT[0])),
  "Tablice BTN_* musza miec ten sam rozmiar"
);

const size_t N = sizeof(BTN_PINS)/sizeof(BTN_PINS[0]);
const unsigned long DEBOUNCE_MS         = 20;
const unsigned long HOLD_FIRST_DELAY_MS = 400;  // po 0.4 s zaczyna powtarzać
const unsigned long HOLD_REPEAT_MS      = 150;  // co 0.15 s kolejny impuls

// proste stany dla debounce
bool lastStable[20];
bool lastRead[20];
unsigned long lastChangeMs[20];

// czasy powtarzania przy przytrzymaniu
unsigned long nextRepeatMs[20];

void setup() {
  // (opcjonalnie) debug na USB
  Serial.begin(9600);

  // UART2 do komunikacji z kontrolerem głównym
  LINK.begin(9600, SERIAL_8N1, UART_RX, UART_TX);

  for (size_t i=0;i<N;i++) {
    pinMode(BTN_PINS[i], USE_PULLUP[i] ? INPUT_PULLUP : INPUT);
    bool s = digitalRead(BTN_PINS[i]); // HIGH = nie wciśnięty przy pull-up
    lastStable[i]   = s;
    lastRead[i]     = s;
    lastChangeMs[i] = millis();
    nextRepeatMs[i] = 0;
  }

  Serial.println(F("Pilot: READY (UART2 @9600)"));
  LINK.println("HELLO"); // prosty sygnał startu (możesz usunąć)
}

void loop() {
  unsigned long now = millis();

  for (size_t i = 0; i < N; ++i) {
    bool r = digitalRead(BTN_PINS[i]);   // przy INPUT_PULLUP: LOW = wciśnięty

    // wykryj zmianę i zacznij odliczanie debounce
    if (r != lastRead[i]) {
      lastRead[i] = r;
      lastChangeMs[i] = now;
    }

    // po DEBOUNCE_MS uznaj zmianę za stabilną
    if ((now - lastChangeMs[i]) >= DEBOUNCE_MS && r != lastStable[i]) {
      lastStable[i] = r;

      if (r == LOW) {  // zdarzenie: WCIŚNIĘCIE
        LINK.print(F("BTN:"));
        LINK.println(BTN_NAMES[i]);

        Serial.print(F("Wcisniety: "));
        Serial.println(BTN_NAMES[i]);

        // przygotuj auto-repeat jeśli włączony dla danego przycisku
        if (AUTO_REPEAT[i]) {
          nextRepeatMs[i] = now + HOLD_FIRST_DELAY_MS;
        } else {
          nextRepeatMs[i] = 0;
        }
      } else {
        // zdarzenie: PUSZCZENIE
        // zatrzymaj auto-repeat
        nextRepeatMs[i] = 0;

        // jeśli chcesz także zdarzenie PUSZCZENIA, odkomentuj:
        /*
        LINK.print(F("REL:"));
        LINK.println(BTN_NAMES[i]);
        */
      }
    }

    // ===== OBSŁUGA PRZYTRZYMANIA (AUTO-REPEAT) =====
    if (AUTO_REPEAT[i] && lastStable[i] == LOW && nextRepeatMs[i] != 0) {
      // porównanie odporne na overflow millis()
      if ((long)(now - nextRepeatMs[i]) >= 0) {
        // traktujemy przytrzymanie jak kolejne "wciśnięcie" tego samego przycisku
        LINK.print(F("BTN:"));
        LINK.println(BTN_NAMES[i]);

        Serial.print(F("Auto-repeat: "));
        Serial.println(BTN_NAMES[i]);

        nextRepeatMs[i] = now + HOLD_REPEAT_MS;
      }
    }
  }
}
